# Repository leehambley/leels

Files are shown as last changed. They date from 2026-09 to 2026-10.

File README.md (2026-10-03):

# leels: single-axis electronic gearbox



A Rust/Embassy port of the gearbox mode of
[NanoEls H5](https://github.com/kachurovskiy/nanoels), cut down to one job:
the Z lead screw follows the spindle at the selected pitch. There is no WiFi,
no other modes, no X/Y axis, no keyboard or joystick, and no GCode.

```
els-core/   hardware-independent logic, no_std, host-tested (cargo test)
firmware/   esp-hal + esp-rtos (Embassy) binary; ESP32-C6 primary, ESP32-S3 secondary
hil/        hardware-in-the-loop tests: drive a board as the display would
docs/       Nextion page layout
```

## Build and flash

```sh
cd els-core && cargo test          # logic tests on the host

cd firmware
cargo run --release                # ESP32-C6 (default, stable Rust): build, flash, monitor
cargo build --release
cargo run --release --features setup-on-boot   # bench test without a display: hotspot at power-up
cargo +esp s3                      # ESP32-S3: needs the Xtensa toolchain (espup)
```

Board-specific values are in `firmware/src/config.rs`: pinout, motion timing,
display and hotspot settings, and `DEFAULTS`, the machine settings used until
you save your own. Machine settings are normally changed without recompiling,
from the setup page (below).
- **C6** pins (ESP32-C6-DevKitC-1): encoder A 10 / B 11 (Z reserved on 7, not read yet), STEP 18, DIR 19, ENA 20 (S2-SVD servo: wired straight to its opto inputs, see `config.rs`), Nextion TX 22 / RX 23. All are 3.3 V only.
- **C6 breadboard build** (`cargo run --release --features breadboard`), for
  test-driving on a solder breadboard with a 74HCT125 under the DevKit
  driving the servo at 5 V: STEP 18, DIR 8, encoder A 21 / B 15 with
  pull-ups fed from GPIO17 (RX, held high). No ENA: the S2-SVD's enable
  needs 24 V, which this setup doesn't have, so it isn't used (the drive
  enables itself). `config.rs` has the IC wiring. A PCB would use the normal
  pinout.
- **S3** pins: NanoEls H5 pinout (encoder 13/14, STEP 35, DIR 42, ENA 41, Nextion TX 43 / RX 44).

The spindle encoder has open-drain outputs, so the ESP32's internal pull-ups
(already enabled) pull A/B up to 3.3 V. No level shifting is needed on either
chip. For anything beyond slow speeds, fit external pull-ups: see
[Speed limits](#speed-limits-compared-with-nanoels-h5).

Logs go to USB-Serial-JTAG, which leaves both UARTs free.

### Breadboard build: servo wiring (S2-SVD CN2)

S2-SVD servo CN2, a 25-pin D-sub, 5 V only: pin 3 brown PP+ and pin 4 green PD+ to the 5 V rail, pin 14 blue PP minus from 74HCT125 pin 6 (STEP, GPIO18), pin 5 grey PD minus from 74HCT125 pin 8 (DIR, GPIO8). Pins 6, 9 and 10 unconnected.

| Breadboard | ESP32-C6 side | Wire | CN2 pin |
|---|---|---|---|
| POWER | 5 V rail | brown, green | 3 PP+, 4 PD+ |
| STEP | GPIO18 → 74HCT125 pin 6 (2Y) | blue | 14 PP− |
| DIR | GPIO8 → 74HCT125 pin 8 (3Y) | grey | 5 PD− |

- The drive's inputs are optocouplers (330 Ω + LED): a low on PP− or PD−
  sinks current from the 5 V rail through the LED and back to ground through
  the 74HCT125. STEP pulses low. Nothing here is above 5 V.
- No ENA: this servo's enable input needs 24 V, and this setup has nothing
  above 5 V, so it isn't used. Set **Pn003 = 1** (the drive enables itself
  at power-up) and leave CN2 6, 9 and 10 unconnected.
- The 74HCT125's OE pins (4 and 10) are tied to GND, so STEP and DIR are
  always passed through.
- **Before fitting the DevKit, cut its header pins 1, 2, 3, 9, 10, 12, 13
  and 19.** Their breadboard strips carry the 74HCT125's tie-offs (5 V,
  GND) or its 5 V outputs. 5 V reaches the ESP32 otherwise (GPIO12 is USB
  D−, and one board was lost this way), and a grounded GPIO9 holds the BOOT
  pin low, so the chip starts in download mode and looks dead. USB still
  works without them.

### Bench debugging without a display

```sh
cargo run --release --features bench
```

Logs all Nextion UART traffic (`nextion tx:` / `nextion rx:`) and repeats a
jog sequence (tap right, tap left, 2 s hold right, 2 s hold left) so STEP and
DIR can be scoped. It doesn't start the hotspot: setup mode
locks out jogging (add `setup-on-boot` for that separately).

### Hardware-in-the-loop tests

The `hil` firmware build takes Nextion touch events over the USB port, into
the same buffer the display's UART fills, so the touch parser, UI, motion
task, RMT and STEP pin all run for real. A second PCNT unit counts the pulses
on the STEP pin inside the chip (no wiring) and the count is logged next to
the planned position. The host tests in `hil/` reset the board, tap
components by their HMI object names, and assert on the text and colours the
firmware sends to the display and on the step counts.

```sh
cd firmware && cargo build --release --features hil
espflash flash --chip esp32c6 target/riscv32imac-unknown-none-elf/release/els
cd ../hil && LEELS_PORT=/dev/cu.usbmodem1101 cargo test
```

Without `LEELS_PORT` the tests are skipped. The `hil` build ignores saved
settings and doesn't read the Nextion UART, and the spindle isn't simulated
yet, so threading while engaged isn't covered. Plug the board straight into
the computer: through chains of hubs, flashing and the tests can fail.

## Operation

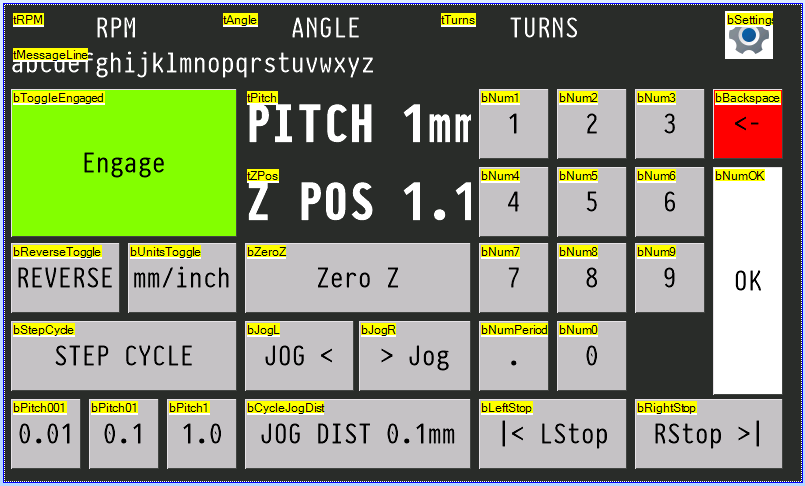
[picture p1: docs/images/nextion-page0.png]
Nextion Editor view of the 800 by 480 touch screen, each component labelled with its object name. Top row: RPM, ANGLE and TURNS readouts and a settings gear. Left: a large green Engage button, REVERSE, mm/inch, STEP CYCLE and pitch presets 0.01, 0.1 and 1.0. Middle: PITCH and Z POS readouts, Zero Z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


The screen layout in the Nextion Editor, with each component's object name.
See [docs/nextion.md](docs/nextion.md) for what each one does.

- **Pitch** is a number plus a unit. Type it on the keypad and press **OK**
  (the pending number shows in amber with a cursor; hold **<-** to clear it),
  or tap a preset (**0.01 / 0.05 / 0.1 / 0.5 / 1.0 / 5.0**). **REVERSE** flips direction.
  **UNIT** keeps the number and changes the unit (0.100 mm becomes 0.100").
  Pitch is capped at 1". Pitch can't be changed while engaged: disengage
  first.
- **Engage / Disengage** is one button: it closes the virtual half-nut at the
  current position, or opens it, stopping the lead screw immediately. The
  thread is kept while disengaged: jog back and engage again at the same pitch
  and the button shows `Syncing` until the spindle reaches the thread's phase,
  so the next pass follows the same groove (single-start threads). Changing
  the pitch while disengaged starts a new thread. Jog a little in the cutting
  direction before engaging to take up lead screw backlash.
- **Stops**: pressing Stop L or Stop R sets that stop at the current position.
  The button turns amber and shows the distance still to go to the stop; it turns red with `AT STOP`
  while the carriage rests on it. Pressing it again clears it, but only while
  disengaged or resting on the stop. Stops limit threading and jogging. The
  carriage parks on a stop while the spindle keeps turning. Reverse the
  spindle and it leaves the stop within one turn, still in thread phase. If
  you clear a stop while resting on it, the engage button shows `Syncing` and
  the carriage waits for the thread phase before moving on. **Zero Z** also
  clears both stops.
- **Jog** (disengaged only; refused with a beep while engaged): **Jog L / Jog R**
  move the carriage. Stops limit jogging too.
  - The jog distance (.01 / .1 / 1 / 10 in the current unit, cycled with its
    own button) also sets the jog speed: 0.5 / 2 / 8 / 25 mm/s.
  - A **tap** moves exactly the jog distance at that speed. Repeated taps add
    up.
  - A **hold** longer than 0.4 s runs continuously, starting at the same speed
    and stepping up one speed every second until 25 mm/s. Releasing brakes to
    a stop. Pressing the other direction while moving also brakes.
  - Speeds and timings are set on the setup page.
- **Setup** (only when disengaged and not jogging) turns on a WiFi hotspot,
  `LEELS-SETUP` with password `els-setup`. Both are shown on the display.
  Phones open the settings page automatically as a sign-in page; otherwise
  browse to `http://192.168.4.1/`. The page covers:
  - the encoder (lines, backlash, glitch filter, direction);
  - the lead screw and motor (pitch, steps, start/max speed, acceleration,
    backlash, largest pitch);
  - driver signals (DIR/ENABLE inversion, STEP polarity, pulse width, DIR
    setup time);
  - jog speeds and timings.

  **Backlash** is taken up on every reversal: the motor turns that much
  further, so the Z readout, stops and thread phase stay true. *Measure it*
  opens a wizard for a dial indicator on the carriage: it moves the carriage
  1 mm left, you zero the indicator, it moves 0.5 mm right, and you enter the
  reading. Each further round runs with the value so far switched on and
  refines it, until a round reads 0.5 mm within 0.005 mm. The carriage moves
  from the phone, so keep hands clear. At power-up the controller assumes the
  slack was last taken up moving left.

  **Save** checks the values, writes them to flash and restarts with WiFi off.
  Pressing Setup again leaves without saving. Pins stay fixed in the firmware.

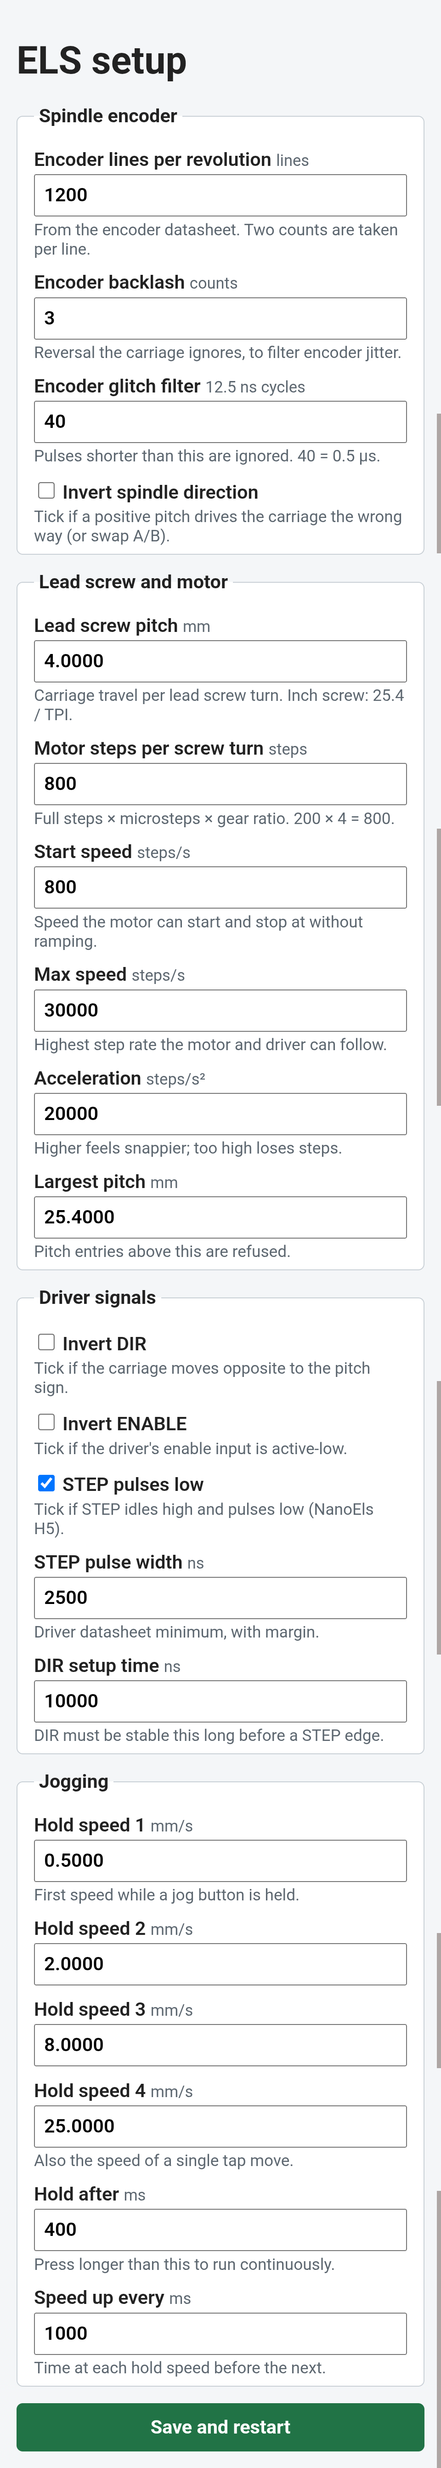
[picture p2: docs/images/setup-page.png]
Setup page on a phone: spindle encoder, lead screw and motor, driver signals and jogging settings, with a Save and restart button
  
- **Remembered across power-off:** pitch, unit, pitch step and jog distance.
  They're saved 3 s after the last change, once the carriage is idle. Stops
  and position are not saved, because the carriage may be moved while the
  controller is off.

## Saved data

Settings and operator state live in the first four sectors of the flash's NVS
partition, as raw records (not ESP-IDF NVS). Each record has:
- a **magic number**, so blank flash (`0xFF`) and random data are told apart;
- a **format version**, for migrations;
- the **length**, a **sequence number** and a **CRC32**.

Two slots per record are written alternately, and the newer valid one wins,
so a power cut during a save keeps the previous copy. Blank flash means
first boot, and the defaults are used. A damaged record, or one from a newer
firmware, also falls back to the defaults, and the display says so. Flash
writes pause the CPU for tens of milliseconds, so they only happen while
nothing moves.

## How motion works

Software plans the motion and hardware times the pulses: the same split as
LinuxCNC's stepgen or Klipper.

```
 PCNT spindle count ─► predict spindle position at end of next segment
                         │
       commands ───────► gearbox (engaged) or jog (disengaged) ─► target
                         │
                       StepGen: velocity/acceleration-limited plan for one
                       250 µs segment → exact STEP pulse times
                         │
                       RMT plays the segment in hardware (100 ns resolution)
                       while the next segment is planned
```

- `motion_task` runs on a high-priority interrupt executor, paced by the RMT
  peripheral. Each loop starts playing the segment planned last time, plans
  the next one, then waits for playback to finish. That's 4,000 wakeups a second.
- The gearbox target is `p_ref + (spindle − s_ref) · pitch·steps / (screw·counts)`,
  in exact integer maths, including the fraction of a step. It's evaluated at
  the spindle position predicted for the end of the segment, so the carriage
  doesn't lag the spindle.
- StepGen (`els-core/src/stepgen.rs`) sets each segment's velocity from:
  - feed-forward: how fast the target is moving;
  - a correction for any remaining error, limited so the error could still be
    braked away (`√(2·a·error)`).

  Velocity is constant within a segment, so pulses are evenly spaced. Host tests
  check a steady spindle gives step intervals within ±0.1 µs of ideal, and that
  a realistic spindle run-up never lags by more than 1 step.
- The maximum step rate is set by the pulse width and the driver (30 k steps/s
  configured), not by a software tick.
- The UI and display run on the normal thread executor. They talk to motion
  through a command channel and a status snapshot.

Known limitation: esp-hal's RMT driver restarts transmission for each
segment, which leaves a few-µs gap between segments. Position isn't affected,
because every step is still planned against the spindle. A gapless version
would need a custom RMT ring-buffer driver.

## Speed limits compared with NanoEls H5

Example machine: a 1200-line encoder driven 1:1 by the spindle (2400 counts
per revolution), 800 steps per screw turn, 4 mm screw (200 steps/mm).
Channel A then runs at **20 Hz per spindle rpm**, and at 1 mm pitch the motor
needs **3.33 steps/s per rpm**.

| | NanoEls H5 original (S3, Arduino) | leels on C6 (primary) | leels on S3 |
|---|---|---|---|
| CPU | 2 × 240 MHz; motion busy-loops on core 1 | 1 × 160 MHz, shared | 2 × 240 MHz; everything on core 0 |
| Encoder counting | PCNT hardware | PCNT hardware | PCNT hardware |
| Encoder glitch filter | 12.5 ns | 0.5 µs (settable) | 0.5 µs (settable) |
| STEP pulses made by | software in `loop()`, polling `micros()` | RMT hardware, 100 ns resolution | RMT hardware, 100 ns resolution |
| Step timing jitter | about one `loop()` pass plus 1 µs `micros()` steps; interrupts on core 1 add to it (estimated) | 0.1 µs within a segment; ~11 µs pause every 250 µs (measured) | same design; pause likely shorter (not measured) |
| Pulse width | length of the code between the two pin writes | exactly as set (2.5 µs default) | exactly as set |
| Step-rate ceiling from the controller | speed of `loop()`: tens of kHz, estimated | 30k steps/s as configured; ~128k possible (32 steps per segment) | same as C6 |
| CPU used by motion | all of core 1 | ~75 µs per 250 µs segment, ~30% (measured) | expected ~20% of core 0 at 240 MHz (not measured) |
| Lag behind the spindle | about one loop pass | ≤ 1 step during spin-up (host tests; position predicted ahead) | same as C6 |

**Maximum rpm is the same on all three.** With hardware pull-ups none of the
controllers is the limit. What is:

1. **The encoder's rated output frequency.** Cheap optical encoders are often
   rated around 100 kHz; check your datasheet. 100 kHz / 20 Hz per rpm =
   **5,000 rpm**. The PCNT counter itself handles MHz rates, and leels'
   0.5 µs glitch filter still passes up to about 1 MHz (50,000 rpm).
2. **The stepper at speed.** A typical stepper at 4× microstepping becomes
   unreliable around 10–15k steps/s (depends on supply voltage and load).
   That's about **3,000–4,500 rpm at 1 mm pitch** and **120–180 rpm at 1"**
   (85 steps/s per rpm). The same motor limits all three controllers.
3. **leels' `speed_max`** (30k steps/s by default) is about 9,000 rpm at
   1 mm pitch, so it's well clear of both.

### Pull-ups and encoder edges

An open-drain output only pulls low. The pull-up resistor and the capacitance
of the cable and input (roughly 100 pF per metre of cable) set how slowly each
edge rises. An input reads high at about 75% of 3.3 V, which takes about
1.4 × R × C.

| Pull-up to 3.3 V | Rise time (1 m cable, ~100 pF) | Rise time (3 m, ~300 pF) | rpm before edges get marginal* |
|---|---|---|---|
| internal, ~45 kΩ | ~6 µs | ~19 µs | ~4,000 (1 m), ~1,300 (3 m) |
| external 4.7 kΩ | ~0.7 µs | ~2 µs | encoder-limited (~5,000) |
| external 2.2 kΩ | ~0.3 µs | ~1 µs | encoder-limited (~5,000) |

\*Rise time equal to half a period of channel A: 1 / (2 × 20 Hz × rpm).
Before that point, slow edges can also count twice if noise crosses the
threshold. This applies equally to the original firmware, which used the
same internal pull-ups.

Use **2.2–4.7 kΩ to 3.3 V, not 5 V**: ESP32 inputs aren't 5 V tolerant, and
at 3.3 V the encoder only has to sink about 1.5 mA.

### Multiple cores

- **C6:** one main core; its second core is a 20 MHz low-power core that can't
  run any of this. Motion runs on a high-priority interrupt executor that
  preempts the display, touch and WiFi tasks, and uses ~30% of the core.
- **S3:** motion *can* be moved to core 1 (`esp_rtos::start_second_core`,
  then start the motion interrupt executor there). It **isn't needed for
  speed**: RMT times the pulses, and planning only has to finish within each
  250 µs segment, which it does with room to spare even on the C6. The only
  benefit would be isolating motion from WiFi interrupts on the S3. Flash
  writes stall both cores regardless, which is why saves only happen while
  idle. Worth doing only if an S3 build ever shows planning overruns.

## Not carried over

Saving stops and position across power-off, backlash compensation, TPI
entry, the max-travel E-stop, and enable/disable per axis.

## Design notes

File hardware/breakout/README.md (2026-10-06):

# Breakout board

A carrier for the ESP32-C6-DevKitC-1: the DevKit plugs into two 1x16 female
sockets (rows 22.86 mm apart) and sits about 8.5 mm above this board. All parts
are through-hole. The buffer IC, transistor, resistors and capacitors sit under
the DevKit, so keep them low: no IC socket, resistors flat.

- Left edge: encoder terminal (bottom to top: 5V, GND, A, B, Z) and shield
  GND terminal.
- Right edge: Nextion (JST-XH 4), servo terminal (5V, STEP, DIR, ENA, GND) and
  5 V in.
- The board stops where the DevKit's PCB stops, so nothing is under its
  antenna.

Firmware: the normal C6 build (`cargo run --release`), not `--features breadboard`.

## Regenerating the PCB

The schematic is the source. The board is rebuilt from it by script, then
routed with [Freerouting](https://github.com/freerouting/freerouting) 1.9.0:

```sh
KP=/Applications/KiCad/KiCad.app/Contents/Frameworks/Python.framework/Versions/3.9/bin/python3
kicad-cli sch export netlist --format kicadxml -o net.xml leels-breakout.kicad_sch
$KP build_pcb.py net.xml         # outline, placement, GND pours, stitching vias
$KP route.py export board.dsn
java -jar freerouting-1.9.0.jar -de board.dsn -do board.ses -mp 100 -inc Ground
$KP route.py import board.ses    # also refills the pours
kicad-cli pcb drc --schematic-parity --refill-zones leels-breakout.kicad_pcb
```

Placement lives in `build_pcb.py` (`PLACE`). GND is not routed; the pours on
both layers and the stitching vias carry it. Net classes (0.3 mm signals,
0.6 mm power and ground) are in `leels-breakout.kicad_pro`.

`leels.pretty/ESP32-C6-DevKitC-1_Sockets` is Espressif's DevKitC-1 footprint
with its courtyard limited to the socket rows, so parts may sit under the
DevKit.

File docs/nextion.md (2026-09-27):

# Nextion page layout

Only page 0 of the Lee-LS HMI (`nextion/lee-ls.HMI`, compiled as
`nextion/lee-ls.tft`) is used. The firmware identifies buttons by
**component id**. The ids live in `els-core/src/nextion.rs::id`; the Nextion
Editor renumbers every component after a deleted one, so re-check them
whenever the HMI changes. Nextion sends `65 00 <id> 01 FF FF FF` on press when *Send
Component ID* is ticked for the Touch Press Event. It writes text by
**objname**. The mapping lives in `els-core/src/nextion.rs::key_for`; the
written fields are in `els-core/src/display.rs::FIELDS`.

See `nextion-hmi-lee-ls.md` for the full component list with geometry,
and the history of the naming decisions.

## Buttons (touch press → action)

| id | objname | action |
|---:|---|---|
| 19 | bToggleEngaged | **Engage** the virtual half-nut when idle (refused while a number is being typed, in setup, or while jogging); **disengage** when engaged or syncing |
| 20 | bReverseToggle | **Reverse**: flip pitch direction |
| 21 | bUnitsToggle | Toggle **MM / IN** (number kept; refused if it would exceed 1") |
| 23 | bPitch001 | Set pitch to 0.01 (current unit and direction), a keypad shortcut |
| 33 | bPitch005 | Set pitch to 0.05 |
| 24 | bPitch01 | Set pitch to 0.1 |
| 34 | bPitch05 | Set pitch to 0.5 |
| 25 | bPitch1 | Set pitch to 1.0 |
| 35 | bPitch5 | Set pitch to 5.0 (inch: refused, over the 1" limit) |
| 6–8, 10–16 | bNum1…bNum9, bNum0 | Digits (`bNum1`=6, `bNum2`=7, `bNum3`=8, `bNum4`…`bNum9`=10…15, `bNum0`=16) |
| 18 | bNumPeriod | Decimal point |
| 9 | bBackspace | Delete the last typed character; **hold ≥ 0.7 s** (on release) to clear the whole entry. Needs press *and* release events |
| 17 | bNumOK | Apply typed pitch |
| 4 | bLeftStop | Set the Z left stop at the current position, or clear it (see *Stops* below) |
| 5 | bRightStop | Same for the right stop |
| 26 | bZeroZ | Zero the Z position readout **and clear both stops** (`Stops cleared` on the message line for 5 s or until the next press). Refused while engaged with a stop set |
| 27 | bJogL | **Jog left**; needs press *and* release events |
| 28 | bJogR | **Jog right**; needs press *and* release events |
| 29 | bCycleJogDist | Cycle jog distance .01 / .1 / 1 / 10 (current unit) |
| 31 | bSettings | Start / leave the WiFi setup hotspot |
| 2, 3 | tAngle, tTurns | Zero turns and angle readouts |

For the two jog buttons and `bBackspace`, tick *Send Component ID* on **both**
Touch Press and Touch Release events. Every other entry above only needs the
press event.

**Pitch is locked while the half-nut is engaged:** digits, `.`, OK, the pitch
presets, REVERSE and mm/inch beep and show `Disengage to change pitch`.

**Keypad entry:** while a number is typed but not yet applied, `tPitch` shows
it with a blinking cursor (`P1.25_`) on an amber background, and the
message line shows `OK to apply, <- delete, hold <- clear`. Any other button
drops the entry and shows `Entry cancelled`; a pitch preset simply replaces it.

**Setup mode:** while the hotspot is up, every touchable component except
`bSettings` has its touch events turned off (`tsw name,0`) and is drawn
near-black with dim grey text. Leaving setup restarts the firmware, which
sends `page 0` at boot to put back the HMI's own colours and touch settings.

## Text and fonts

Text is sent as UTF-8, the encoding of both fonts in the HMI. A font only
shows the glyphs it was generated with:

- **Font 0** (PragmataPro 30 px, all characters): everything except the two
  big readouts. Needs `°` for `tAngle`.
- **Font 1** (PragmataPro Bold 56 px, `tPitch` and `tZPos`): ASCII only.
  About 9 characters fit, which is why the readouts are `P-5.000mm` and
  `Z-999.995` rather than words (`PITCH_SYMBOL` / `Z_SYMBOL` in
  `els-core/src/display.rs`). The bold PragmataPro has almost no symbols;
  the regular weight has e.g. `∿` and `↔` if you ever regenerate the font.

## Text written by the firmware

| objname | content |
|---|---|
| bToggleEngaged | `Engage`, `Disengage` (engaged), `Syncing` (waiting for thread phase) or `Setup on` |
| tPitch | `P-1.250mm`; while typing `P1.25_` (blinking cursor, amber) |
| bReverseToggle | `NORMAL` (grey) / `REVERSE` (amber) |
| tMessageLine | (max 40 chars) the typed number (`Pitch 1.25`), warnings, `Set pitch`, `Waiting for thread phase`, and the hotspot name and password in setup mode |
| bUnitsToggle | `UNIT: MM` / `UNIT: IN` (max 10 chars) |
| tRPM | `RPM 1200` |
| tTurns | `TURNS 12.34`, spindle turns since engage (or last zero) |
| tAngle | `ANGLE 123.45°` |
| tZPos | `Z1.123` (mm 3 dp / inch 4 dp; no unit, see tPitch or UNIT) |
| bLeftStop | `\|< Set stop`, `\|< 12.345mm` (distance from the carriage to the stop), or `\|< AT STOP`; max 15 chars |
| bRightStop | `Set stop >\|`, `12.345mm >\|`, or `AT STOP >\|` |
| bCycleJogDist | idle: `JOG DIST 0.1mm`; tap move: `JOG 0.300mm` (distance still to go); hold: `HOLD SPEED 2/4`; braking: `STOPPING` |

Fields are only resent when their
text changes, plus a full refresh every 5 s.

## Stops

Each stop button has three states. The firmware sets the caption and the
background (`bco`) and text (`pco`) colours. Every pair meets WCAG AAA
(≥ 7:1 contrast) for poor workshop lighting; a unit test enforces it:

| State | Caption | `bco` | Tap |
|---|---|---|---|
| Not set | `\|< Set stop` | grey `50712` / black text (11.9:1) | set the stop at the current position |
| Set | `\|< 12.345mm` = the stop's Z position (same zero and units as `tZPos`) | amber `64896` / black text (11.6:1) | clear it, **only while disengaged**; otherwise beep + `Stop armed: wait or disengage` |
| Parked (carriage is at the stop) | `\|< AT STOP` | dark red `40960` / white text (8.1:1) | clear it: when threading, the carriage waits for thread phase and continues |

"Parked" means the motor position equals the stop: either a threading pass
ended there, or a jog ran into it.

Messages on `tMessageLine` disappear after their timeout or on the next
button press (jog releases don't count).

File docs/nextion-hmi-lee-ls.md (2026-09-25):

# Lee-LS HMI → firmware mapping

> **Historical.** This compared an earlier revision of the HMI with the
> firmware before it was adapted. The committed HMI (`nextion/lee-ls.HMI`)
> has a different layout, no `tSpeed`, an added `tMessageLine`, and ids shifted
> by one. `docs/nextion.md` is the current reference.

This compares `Lee-LS HMI.grid.HMI` (page 0, 33 components) with the
current firmware: `els-core/src/nextion.rs::key_for`, the `Key` enum in
`els-core/src/ui.rs`, `els-core/src/display.rs::FIELDS`, and
`docs/nextion.md`.

**Status:** §2, §3 and §5 are implemented in `els-core`, using the
decisions: bPitch buttons are pitch presets (`Key::PitchPreset`), messages
go to the added `tMessageLine` (40 chars), `tSpeed` is dropped (remove it from the HMI).

Component ids come from the HMI's `id` attribute (hex in the file,
decimal below). The grid version has the same ids as the original.

> **Check in the Editor:** the "Send Component ID" flags on the Touch
> Press/Release events were not decoded from the HMI. Every button below
> needs *Press* ticked. `bJogL`/`bJogR` also need *Release* ticked, and so
> do `tTurns`/`tAngle` if they stay tappable.

## 1. Component list

| id | objname | type | label in HMI | font | geometry (x,y w×h) |
|---:|---|:-:|---|:-:|---|
| 1 | `tRPM` | t | RPM | 0 | 14,6 148×30 |
| 2 | `tSpeed` | t | SPEED | 0 | 170,6 148×30 (dropped, to be removed) |
| 3 | `tAngle` | t | ANGLE | 0 | 326,6 148×30 |
| 4 | `tTurns` | t | TURNS | 0 | 482,6 148×30 |
| 5 | `bLeftStop` | b | \|< LStop | 0 | 482,396 148×70 |
| 6 | `bRightStop` | b | RStop >\| | 0 | 638,396 148×70 |
| 7 | `bNum1` | b | 1 | 0 | 482,84 70×70 |
| 8 | `bNum2` | b | 2 | 0 | 560,84 70×70 |
| 9 | `bNum3` | b | 3 | 0 | 638,84 70×70 |
| 10 | `bBackspace` | b | <- | 0 | 716,84 70×70 |
| 11 | `bNum4` | b | 4 | 0 | 482,162 70×70 |
| 12 | `bNum5` | b | 5 | 0 | 560,162 70×70 |
| 13 | `bNum6` | b | 6 | 0 | 638,162 70×70 |
| 14 | `bNum7` | b | 7 | 0 | 482,240 70×70 |
| 15 | `bNum8` | b | 8 | 0 | 560,240 70×70 |
| 16 | `bNum9` | b | 9 | 0 | 638,240 70×70 |
| 17 | `bNum0` | b | 0 | 0 | 560,318 70×70 |
| 18 | `bNumOK` | b | OK | 0 | 716,162 70×226 |
| 19 | `bNumPeriod` | b | . | 0 | 482,318 70×70 |
| 20 | `bToggleEngaged` | b | Engage | 0 | 14,84 226×148 |
| 21 | `bReverseToggle` | b | REVERSE | 0 | 14,240 109×70 |
| 22 | `bUnitsToggle` | b | mm/inch | 0 | 131,240 109×70 |
| 23 | `bStepCycle` | b | STEP CYCLE | 0 | 14,318 226×70 |
| 24 | `tPitch` | t | PITCH 1mm | 1 | 248,84 226×70 |
| 25 | `bPitch001` | b | 0.01 | 0 | 14,396 70×70 |
| 26 | `bPitch01` | b | 0.1 | 0 | 92,396 70×70 |
| 27 | `bPitch1` | b | 1.0 | 0 | 170,396 70×70 |
| 28 | `bZeroZ` | b | Zero Z | 0 | 248,240 226×70 |
| 29 | `bJogL` | b | JOG < | 0 | 248,318 109×70 |
| 30 | `bJogR` | b | > Jog | 0 | 365,318 109×70 |
| 31 | `bCycleJogDist` | b | JOG DIST 0.1mm | 0 | 248,396 226×70 |
| 32 | `tZPos` | t | Z POS 1.123mm | 1 | 248,162 226×70 |
| 33 | `bSettings` | b | CFG | 0 | 716,6 70×70 |

## 2. Touch → `Key` mapping

**Status** key:
- ✅ same action; only the id or name changed
- 🆕 needs a new `Key` variant or new logic
- ❓ needs your decision

| id | objname | → Key | old firmware id / name | status |
|---:|---|---|---|:-:|
| 7–9, 11–16, 17 | `bNum1`…`bNum9`, `bNum0` | `Digit(n)` | 26–35, `b0`…`b9` | ✅ ids are **no longer contiguous**, so `c @ 26..=35` must become an explicit table (§5) |
| 19 | `bNumPeriod` | `Point` | 52 `bPoint` | ✅ |
| 10 | `bBackspace` | `Backspace` | 24 `bBack` | ✅ |
| 18 | `bNumOK` | `Enter` | 51 `bEnter` | ✅ |
| 20 | `bToggleEngaged` | **`ToggleEngage`** | 25 `bOn` / 23 `bOff` / 3 `bStatus` | 🆕 one button replaces three: engage when off, disengage when on or syncing. Keep the "refused while typing" rule for the engage direction. |
| 21 | `bReverseToggle` | `Reverse` | 5 `bReverse` | ✅ |
| 22 | `bUnitsToggle` | `ToggleUnit` | 6 `bMeasure` | ✅ |
| 23 | `bStepCycle` | `CycleStep` | 7 `tStepVal` | ✅ |
| 25 | `bPitch001` (0.01) | `StepSize(1)` | 54 `bStep01` | ❓ see §4.1 |
| 26 | `bPitch01` (0.1) | `StepSize(2)` | 55 `bStep1` | ❓ see §4.1 |
| 27 | `bPitch1` (1.0) | `StepSize(3)` | 56 `bStep10` | ❓ see §4.1 |
| 5 | `bLeftStop` | `StopLeft` | 40 `bStopL` | ✅ |
| 6 | `bRightStop` | `StopRight` | 41 `bStopR` | ✅ |
| 28 | `bZeroZ` | `ZeroZ` | 21 `bZ0` | ✅ |
| 29 | `bJogL` | `Jog { left: true, .. }` | 48 `bLeft` | ✅ press **and** release |
| 30 | `bJogR` | `Jog { left: false, .. }` | 49 `bRight` | ✅ press **and** release |
| 31 | `bCycleJogDist` | `JogCycle` | 58 `bJogDist` | ✅ |
| 33 | `bSettings` | `Setup` | 59 `bSetup` | ✅ |
| 3, 4 | `tAngle`, `tTurns` | `ZeroTurns` | 10, 9 (same names) | ✅ ids changed (10→3, 9→4) |
| 1, 2, 24, 32 | `tRPM`, `tSpeed`, `tPitch`, `tZPos` | none | none | not touch targets |

**Firmware keys with no HMI button:**

| Key | old id / name | note |
|---|---|---|
| `Plus` | 42 `bPlus` | ❓ no +/- buttons, see §4.1 |
| `Minus` | 43 `bMinus` | ❓ |
| `StepSize(0)` (0.001) | 53 `bStep001` | only reachable through `bStepCycle` |
| `StepSize(4)` (10) | 57 `bStep100` | only reachable through `bStepCycle` |
| `Engage` / `Disengage` | 25 / 23 | replaced by `ToggleEngage`. Keep them internally if the web UI or other code uses them. |

## 3. Text written by the firmware (`display.rs::FIELDS`)

| Firmware field | Content today | New target | status |
|---|---|---|:-:|
| `bStatus` | `OFF`/`ON`/`SYN`/`SET` | `bToggleEngaged.txt` | 🆕 suggest showing the action or state on the big button, e.g. `ENGAGE` when off, `ON` / `SYNC…` / `SETUP` otherwise |
| `tPitch` | `-1.250` | `tPitch.txt` | ✅ name matches. The HMI placeholder is `PITCH 1mm`, so the firmware probably needs to prefix/suffix it (`PITCH -1.250mm`). |
| `bMeasure` | `MM`/`IN` | `bUnitsToggle.txt` | ✅ rename |
| `tStepVal` | `0.001`…`10` | `bStepCycle.txt`? | ❓ no dedicated field. Suggest `STEP 0.1` on the cycle button. |
| `tRPMVal` | rpm | `tRPM.txt` | 🆕 one field holds label and value, e.g. `RPM 1200` |
| `tTurnsVal` | turns | `tTurns.txt` | 🆕 e.g. `TURNS 12.34` |
| `tAngleVal` | angle ° | `tAngle.txt` | 🆕 e.g. `ANGLE 123.45°` |
| none | none | `tSpeed.txt` | dropped: not a firmware value (the H5 had no speed field either) |
| `tZ` | Z position | `tZPos.txt` | ✅ rename. Placeholder `Z POS 1.123mm` suggests the same prefix/suffix treatment as `tPitch`. |
| `tZLeft` | distance to left stop | `bLeftStop.txt`? | ❓ no field. Could show `\|< 12.345` once set and `\|< LStop` when unset. |
| `tZRight` | distance to right stop | `bRightStop.txt`? | ❓ as above |
| `tJogVal` | `0.01`…`10` | `bCycleJogDist.txt` | 🆕 placeholder is `JOG DIST 0.1mm` |
| `t3` | typed number, warnings, `Set pitch`, hotspot SSID/password | **none** | ❓ biggest gap, see §4.2 |

## 4. Open decisions

### 4.1 Pitch step buttons without +/-

`StepSize` only affects `Plus`/`Minus`, and the HMI has no +/- buttons.
The buttons labelled `0.01`, `0.1`, and `1.0` therefore do nothing
visible under the current firmware. Options:

- **a)** Add `bPitchPlus`/`bPitchMinus` to the HMI. There is no free
  cell in the grid, so something would have to shrink.
- **b)** Make them *pitch presets*: tapping `1.0` sets pitch to 1.0 mm.
  This needs a new `Key::PitchPreset(milli)`.
- **c)** Make them the **jog distance** selector instead, and drop
  `bCycleJogDist`. The values match `JOG_SIZES_MILLI` (0.01/0.1/1/10
  minus 10).
- **d)** Leave them as step-size selectors for a future +/- (knob or
  encoder).

`bStepCycle` has the same issue: it cycles a step size that nothing uses
until +/- exists.

### 4.2 No message line (`t3`)

`t3` carries:
- the number being typed (`Pitch 1.25`), the only feedback while using
  the keypad;
- warnings ("refused while typing", unit overflow);
- `Set pitch`;
- `Waiting for thread phase`;
- the setup hotspot name and password.

Options:

- **a)** While typing, and for timed messages, show them in `tPitch`
  (it is the biggest text field and sits next to the keypad), then
  revert to the pitch. Show setup credentials there too while
  `setup_active()`. This needs firmware only.
- **b)** Add a message text field to the HMI, e.g. a 1-row strip. The
  grid has no free row, so something has to shrink.

(a) seems the better fit for this layout.

### 4.3 Status display

With `bStatus` gone, the toggle button's own text is the only engaged
indicator. The HMI could also change its `bco` when engaged: the
firmware would send `bToggleEngaged.bco=<rgb565>`. `encode_text` only
does `.txt`, so a small `encode_num` would be needed.

## 5. Suggested `key_for`

```rust
pub fn key_for(touch: Touch) -> Option<Key> {
    if touch.page != 0 {
        return None;
    }
    match touch.component {
        29 => return Some(Key::Jog { left: true, pressed: touch.pressed }),  // bJogL
        30 => return Some(Key::Jog { left: false, pressed: touch.pressed }), // bJogR
        _ if !touch.pressed => return None,
        _ => {}
    }
    Some(match touch.component {
        7 => Key::Digit(1),
        8 => Key::Digit(2),
        9 => Key::Digit(3),
        11 => Key::Digit(4),
        12 => Key::Digit(5),
        13 => Key::Digit(6),
        14 => Key::Digit(7),
        15 => Key::Digit(8),
        16 => Key::Digit(9),
        17 => Key::Digit(0),
        19 => Key::Point,        // bNumPeriod
        10 => Key::Backspace,    // bBackspace
        18 => Key::Enter,        // bNumOK
        20 => Key::ToggleEngage, // bToggleEngaged (new variant)
        21 => Key::Reverse,      // bReverseToggle
        22 => Key::ToggleUnit,   // bUnitsToggle
        23 => Key::CycleStep,    // bStepCycle
        25 => Key::StepSize(1),  // bPitch001 "0.01"  -- see 4.1
        26 => Key::StepSize(2),  // bPitch01  "0.1"
        27 => Key::StepSize(3),  // bPitch1   "1.0"
        5 => Key::StopLeft,      // bLeftStop
        6 => Key::StopRight,     // bRightStop
        28 => Key::ZeroZ,        // bZeroZ
        31 => Key::JogCycle,     // bCycleJogDist
        33 => Key::Setup,        // bSettings
        3 | 4 => Key::ZeroTurns, // tAngle, tTurns
        _ => return None,
    })
}
```

And the matching `FIELDS`, pending §4:

```rust
pub const FIELDS: [&str; N] = [
    "bToggleEngaged", // status
    "tPitch",
    "bUnitsToggle",   // was bMeasure
    "bStepCycle",     // was tStepVal
    "tRPM",           // was tRPMVal
    "tTurns",         // was tTurnsVal
    "tAngle",         // was tAngleVal
    "tZPos",          // was tZ
    "bLeftStop",      // was tZLeft
    "bRightStop",     // was tZRight
    "bCycleJogDist",  // was tJogVal
    "tSpeed",         // new
    // t3 message line: see 4.2
];
```

`docs/nextion.md` also describes the old H5-derived ids ("ids below 51
are the existing NanoEls H5 ids"). That no longer holds: this HMI
renumbers from 1. Update or replace it once the decisions above are made.

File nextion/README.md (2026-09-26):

# Nextion display files

| File | What |
|---|---|
| `lee-ls.HMI` | Nextion Editor project for the 800×480 NX8048P050-011R-Y display. Edit this. |
| `lee-ls.tft` | The same project compiled by the Nextion Editor, ready to load onto the display. |
| `SHA256SUMS` | Checksums of both, so you can tell the pair belongs together (`shasum -a 256 -c SHA256SUMS`). |

The `.tft` was compiled from this exact `.HMI`: every component's geometry in
the HMI appears in the `.tft`'s compiled page, and its compiled components
are in the HMI's id order (1–35).

**When you change the HMI:** recompile the `.tft`, replace both files
together, and regenerate `SHA256SUMS`. If you added or deleted a component,
the Editor renumbers everything after it: update the ids in
`els-core/src/nextion.rs` (`mod id`) and `docs/nextion.md` to match.

To load the `.tft`, copy it to a FAT32 microSD card, put the card in the
display and power it up, or upload it over serial from the Nextion Editor.

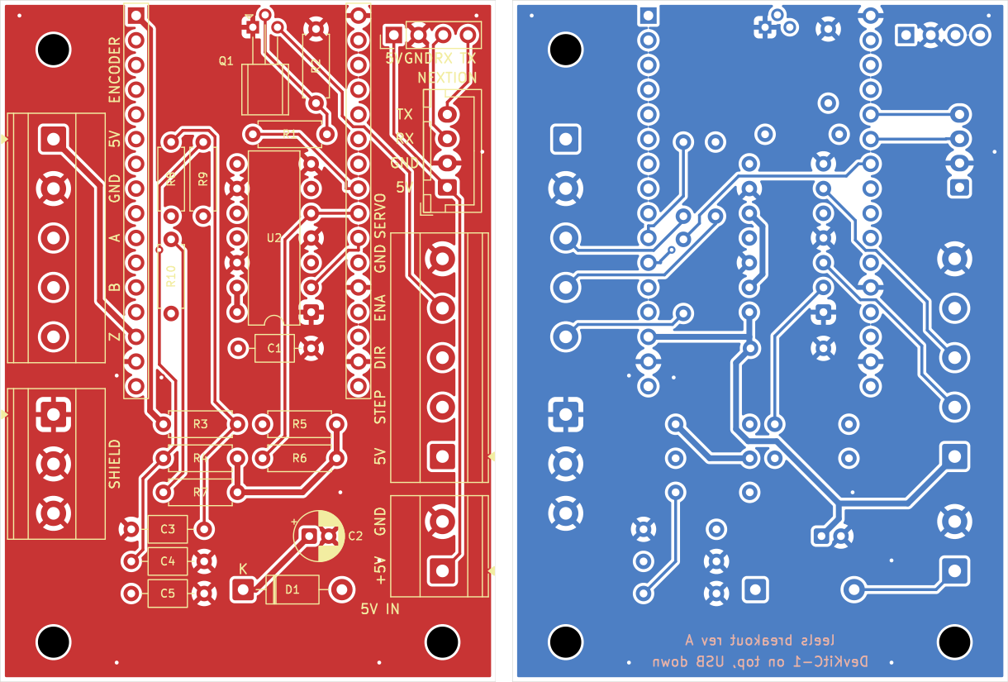
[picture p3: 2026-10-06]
hardware/breakout/leels-breakout-pcb.png

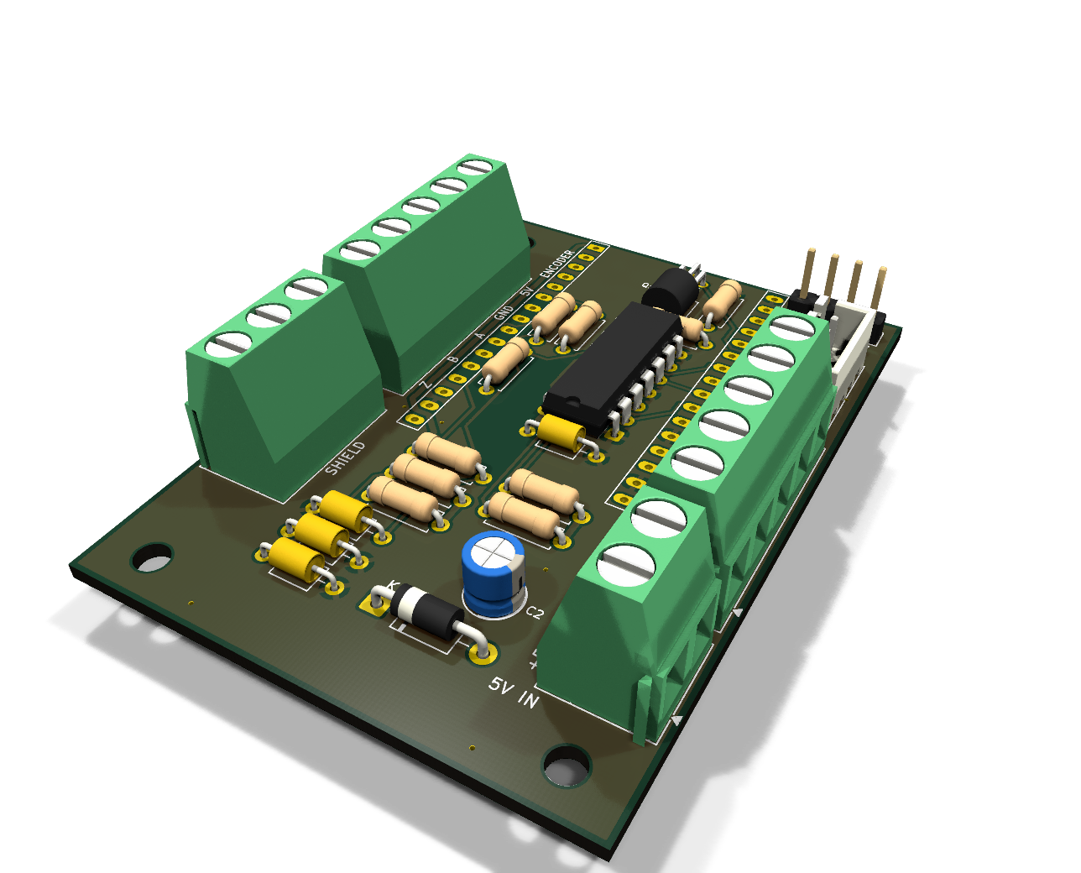
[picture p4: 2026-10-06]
hardware/breakout/leels-breakout-3d.png

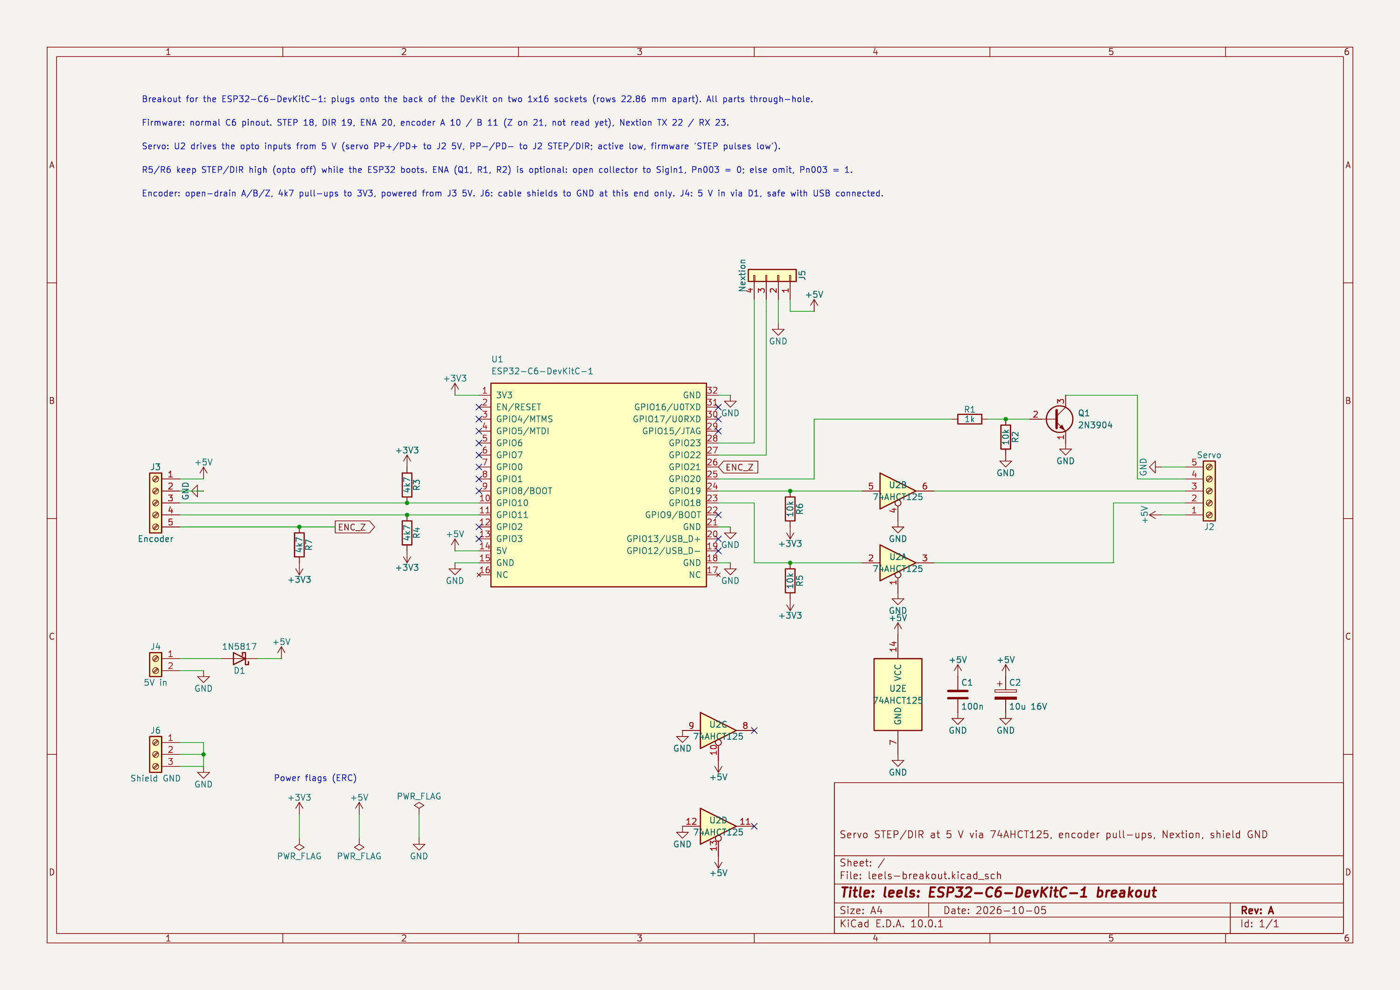
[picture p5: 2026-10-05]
hardware/breakout/leels-breakout.png

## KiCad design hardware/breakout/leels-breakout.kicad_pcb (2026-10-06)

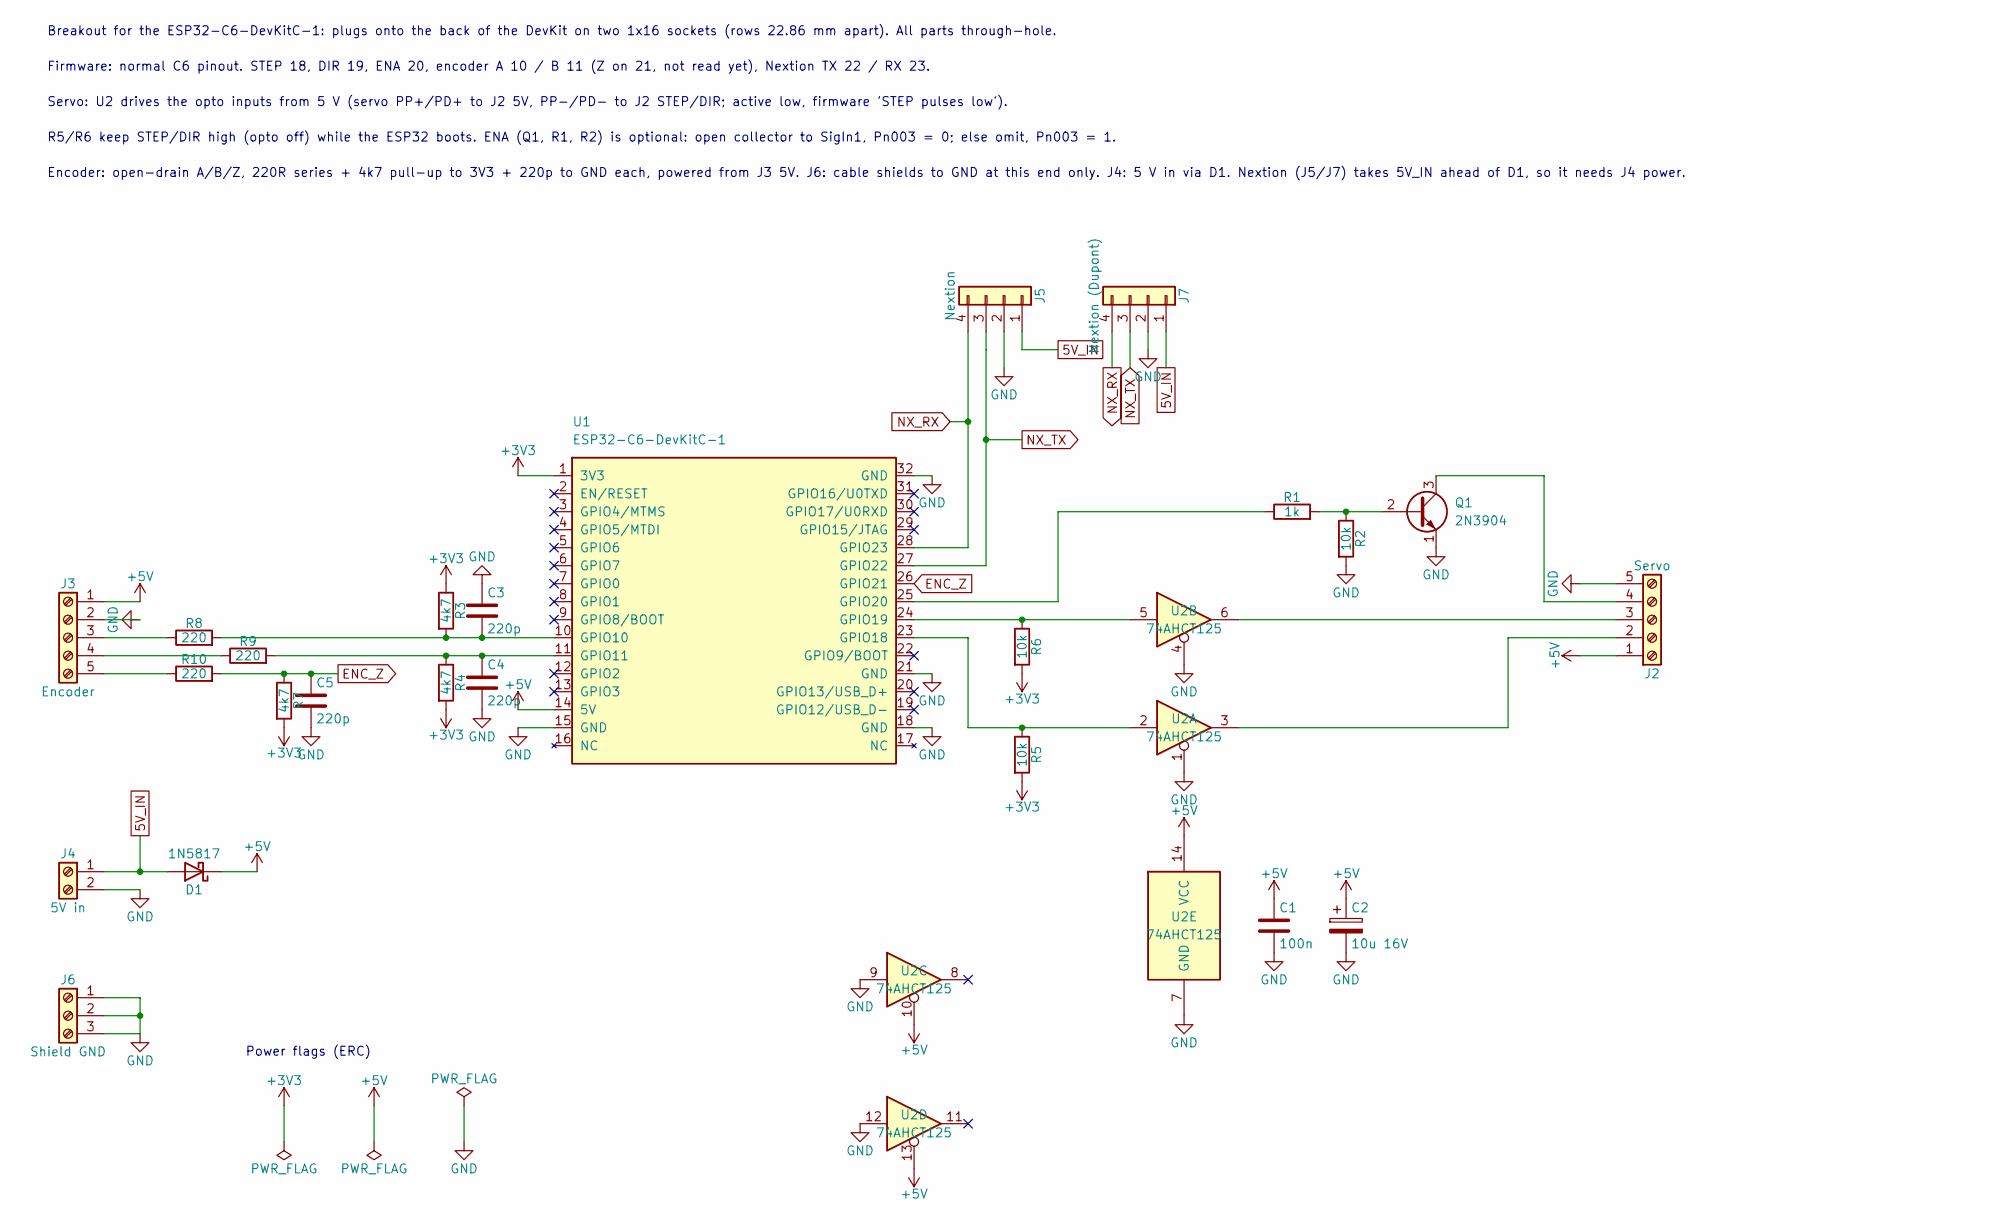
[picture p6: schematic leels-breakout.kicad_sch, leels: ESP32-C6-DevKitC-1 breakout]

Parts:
C1: 100n; C_Axial_L3.8mm_D2.6mm_P7.50mm_Horizontal
C2: 10u 16V; CP_Radial_D5.0mm_P2.00mm
C3, C4, C5: 220p; C_Axial_L3.8mm_D2.6mm_P7.50mm_Horizontal
D1: 1N5817; D_DO-41_SOD81_P10.16mm_Horizontal
J2: Servo; TerminalBlock_Phoenix_MKDS-1,5-5-5.08_1x05_P5.08mm_Horizont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
J3: Encoder; TerminalBlock_Phoenix_MKDS-1,5-5-5.08_1x05_P5.08mm_Horizont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
J4: 5V in; TerminalBlock_Phoenix_MKDS-1,5-2-5.08_1x02_P5.08mm_Horizont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
J5: Nextion; JST_XH_B4B-XH-A_1x04_P2.50mm_Vertical
J6: Shield GND; TerminalBlock_Phoenix_MKDS-1,5-3-5.08_1x03_P5.08mm_Horizont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
J7: Nextion (Dupont); PinHeader_1x04_P2.54mm_Vertical
Q1: 2N3904; TO-92_W4.0mm_StaggerEven_Horizontal_FlatSideDown
R1: 1k; R_Axial_DIN0207_L6.3mm_D2.5mm_P7.62mm_Horizontal
R2, R5, R6: 10k; R_Axial_DIN0207_L6.3mm_D2.5mm_P7.62mm_Horizontal
R3, R4, R7: 4k7; R_Axial_DIN0207_L6.3mm_D2.5mm_P7.62mm_Horizontal
R8, R9, R10: 220; R_Axial_DIN0207_L6.3mm_D2.5mm_P7.62mm_Horizontal
U1: ESP32-C6-DevKitC-1; ESP32-C6-DevKitC-1_Sockets
U2: 74AHCT125; DIP-14_W7.62mm

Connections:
5V_IN: D1.2 (A), J4.1, J5.1, J7.1
+3V3: R3.1, R4.2, R5.2, R6.2, R7.2, U1.1 (3V3)
+5V: C1.1, C2.1, D1.1 (K), J2.1, J3.1, U1.14 (5V), U2.10, U2.13, U2.14 (VCC)
ENC_Z: C5.1, R7.1, R10.2, U1.26 (GPIO21)
GND: C1.2, C2.2, C3.1, C4.2, C5.2, J2.5, J3.2, J4.2, J5.2, J6.1, J6.2, J6.3, J7.2, Q1.1 (E), R2.2, U1.15 (GND), U1.18 (GND), U1.21 (GND), U1.32 (GND), U2.1, U2.4, U2.7 (GND), U2.9, U2.12
NX_RX: J5.4, J7.4, U1.28 (GPIO23)
NX_TX: J5.3, J7.3, U1.27 (GPIO22)
unnamed: J2.2, U2.3
unnamed: J2.3, U2.6
unnamed: J2.4, Q1.3 (C)
unnamed: J3.3, R8.1
unnamed: J3.4, R9.1
unnamed: J3.5, R10.1
unnamed: Q1.2 (B), R1.2, R2.1
unnamed: C3.2, R3.2, R8.2, U1.10 (GPIO10)
unnamed: C4.1, R4.1, R9.2, U1.11 (GPIO11)
unnamed: R5.1, U1.23 (GPIO18), U2.2
unnamed: R6.1, U1.24 (GPIO19), U2.5
unnamed: R1.1, U1.25 (GPIO20)

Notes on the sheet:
Breakout for the ESP32-C6-DevKitC-1: plugs onto the back of the DevKit on two 1x16 sockets (rows 22.86 mm apart). All parts through-hole.
Firmware: normal C6 pinout. STEP 18, DIR 19, ENA 20, encoder A 10 / B 11 (Z on 21, not read yet), Nextion TX 22 / RX 23.
Servo: U2 drives the opto inputs from 5 V (servo PP+/PD+ to J2 5V, PP-/PD- to J2 STEP/DIR; active low, firmware 'STEP pulses low').
R5/R6 keep STEP/DIR high (opto off) while the ESP32 boots. ENA (Q1, R1, R2) is optional: open collector to SigIn1, Pn003 = 0; else omit, Pn003 = 1.
Encoder: open-drain A/B/Z, 220R series + 4k7 pull-up to 3V3 + 220p to GND each, powered from J3 5V. J6: cable shields to GND at this end only. J4: 5 V in via D1. Nextion (J5/J7) takes 5V_IN ahead of D1, so it needs J4 power.
Power flags (ERC)

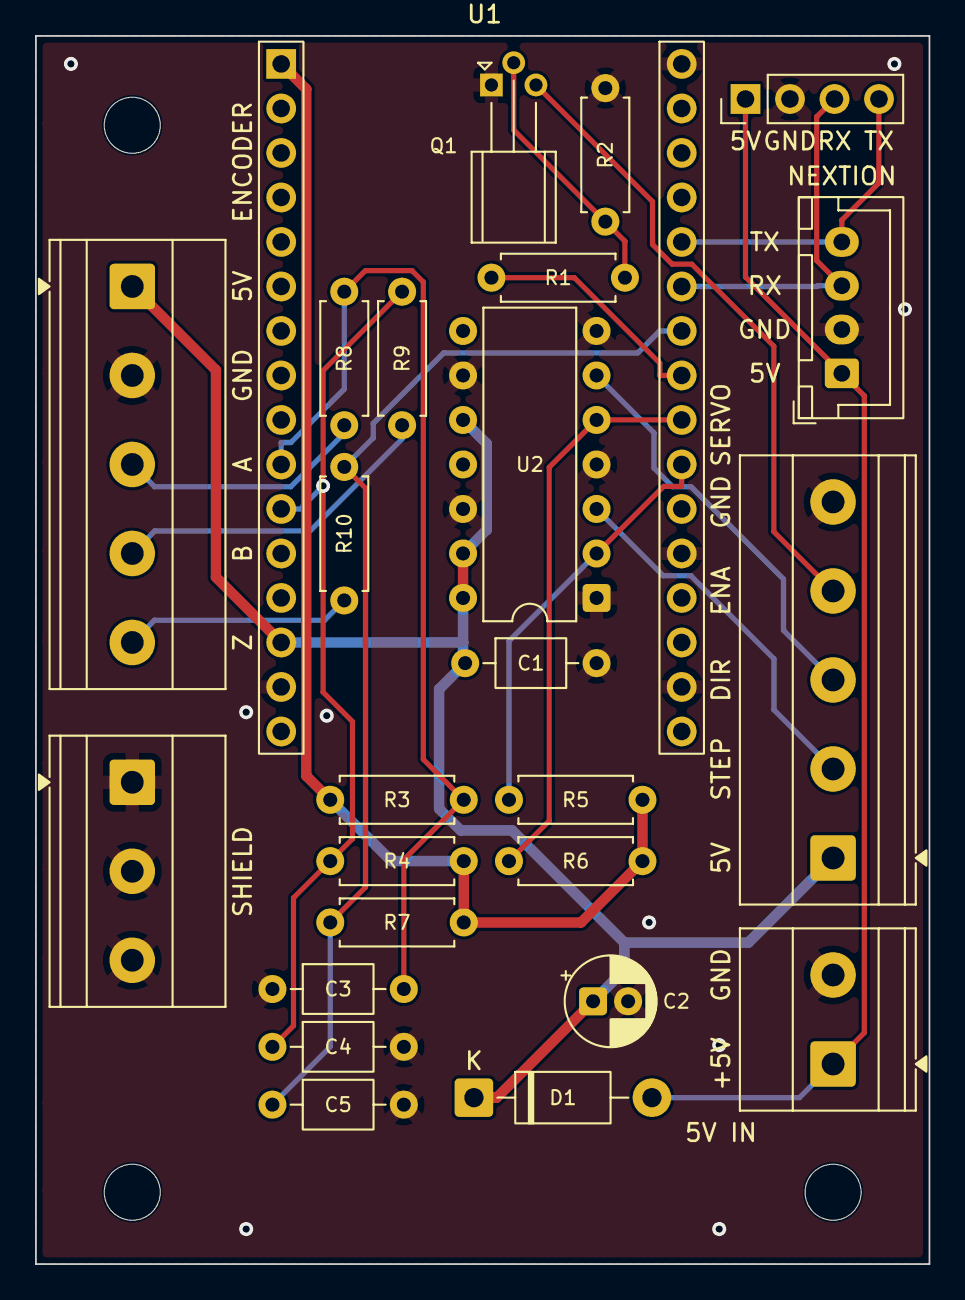
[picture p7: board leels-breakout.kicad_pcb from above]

Board: 2 copper layers, 51.0 x 70.1 mm, 28 parts (0 on the bottom side), 19 nets.

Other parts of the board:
H1, H2, H3: MountingHole_3.2mm_M3

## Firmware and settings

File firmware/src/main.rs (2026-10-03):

//! Single-axis electronic gearbox: the Z lead screw follows the spindle at the
//! selected pitch while the virtual half-nut is engaged.
//!
//! Motion pipeline (all on a high-priority interrupt executor):
//!
//! ```text
//!  PCNT spindle count ──► predict spindle at end of next segment
//!                           │
//!        commands ────────► gearbox (engaged) or jog (disengaged) ──► target
//!                           │
//!                         StepGen: velocity/accel-limited plan for one
//!                         segment → exact STEP pulse times
//!                           │
//!                         RMT plays the segment in hardware (100 ns
//!                         resolution) while the next one is planned
//! ```
//!
//! The loop is paced by RMT: each iteration starts playing the segment
//! planned last time, plans the following one, then waits for playback to
//! finish. The UI and display run as ordinary tasks on the thread executor.
#![no_std]
#![no_main]

extern crate alloc;

#[macro_use]
mod config;
#[cfg(feature = "hil")]
mod hil;
#[cfg(feature = "esp32c6")]
mod led;
mod setup;
mod storage;

use core::cell::Cell;

use els_core::backlash::Backlash;
use els_core::display::{self, Status, Text, COLOUR_FIELDS, FIELDS};
use els_core::gearbox::{Gearbox, Side};
use els_core::jog::{Bounds, Jog, JogView};
use els_core::nextion::{self, Parser};
use els_core::settings::{Origin, Settings};
use els_core::spindle::Spindle;
use els_core::stepgen::{Segment, StepGen, StepGenConfig, MAX_STEPS_PER_SEGMENT};
use els_core::ui::{Action, Command, Key, Ui};
use embassy_executor::Spawner;
use embassy_futures::select::{select3, Either3};
use embassy_sync::blocking_mutex::raw::CriticalSectionRawMutex;
use embassy_sync::blocking_mutex::Mutex;
use embassy_sync::channel::Channel;
use embassy_sync::pipe::Pipe;
use embassy_time::{Duration, Instant, Timer};
use esp_backtrace as _;
use esp_hal::clock::CpuClock;
use esp_hal::gpio::{Flex, Input, InputConfig, Level, Output, OutputConfig, Pull};
use esp_hal::interrupt::software::SoftwareInterruptControl;
use esp_hal::interrupt::Priority;
use esp_hal::pcnt::{channel, unit::Unit, Pcnt};
use esp_hal::rmt::{self, PulseCode, Rmt, TxChannelConfig, TxChannelCreator};
use esp_hal::time::Rate;
use esp_hal::timer::timg::TimerGroup;
use esp_hal::uart::{self, Uart};
use esp_hal::Async;
use esp_println::println;
use esp_rtos::embassy::InterruptExecutor;
use static_cell::StaticCell;

esp_bootloader_esp_idf::esp_app_desc!();

static COMMANDS: Channel<CriticalSectionRawMutex, Command, 16> = Channel::new();
static KEYS: Channel<CriticalSectionRawMutex, Key, 16> = Channel::new();
/// Bytes from the display, parsed into touch events by `touch_task`. Filled
/// from the Nextion UART, or from USB in `hil` builds.
static NEXTION_RX: Pipe<CriticalSectionRawMutex, 128> = Pipe::new();
/// Bytes for the display, written to the UART by `display_task`. Big enough
/// for a full refresh queued while the display boots.
static NEXTION_TX: Pipe<CriticalSectionRawMutex, 1024> = Pipe::new();
static STATUS: Mutex<CriticalSectionRawMutex, Cell<Status>> = Mutex::new(Cell::new(Status {
    engaged: false,
    syncing: false,
    jogging: false,
    jog: JogView::Idle,
    pos: 0,
    z_zero: 0,
    left_stop: None,
    right_stop: None,
    rpm: 0,
    turn_counts: 0,
}));

/// STEP levels: (active, idle).
fn step_levels(s: &Settings) -> (Level, Level) {
    if s.step_active_low {
        (Level::Low, Level::High)
    } else {
        (Level::High, Level::Low)
    }
}

/// RMT items for one segment: one per step plus the trailing idle/end item.
type Codes = heapless::Vec<PulseCode, { MAX_STEPS_PER_SEGMENT + 1 }>;

struct MotionHw {
    spindle: Unit<'static, 0>,
    // The RMT channel handle isn't `Send`, so it's configured inside the task.
    rmt: esp_hal::peripherals::RMT<'static>,
    step: esp_hal::gpio::interconnect::OutputSignal<'static>,
    #[cfg(feature = "hil")]
    step_counter: hil::StepCounter,
    dir: Flex<'static>,
    // Held so the pins stay configured.
    _enable: Option<Output<'static>>,
    _encoder_a: Input<'static>,
    _encoder_b: Input<'static>,
}

#[esp_rtos::main]
async fn main(spawner: Spawner) {
    #[allow(unused_mut)]
    let mut p = esp_hal::init(esp_hal::Config::default().with_cpu_clock(CpuClock::max()));
    let timg0 = TimerGroup::new(p.TIMG0);
    let sw = SoftwareInterruptControl::new(p.SW_INTERRUPT);
    #[cfg(feature = "esp32c6")]
    esp_rtos::start(timg0.timer0, sw.software_interrupt0);
    #[cfg(feature = "esp32s3")]
    esp_rtos::start(timg0.timer0);
    println!("ELS gearbox starting");

    // Heap for the WiFi stack (only used in setup mode).
    esp_alloc::heap_allocator!(#[esp_hal::ram(reclaimed)] size: 64 * 1024);
    esp_alloc::heap_allocator!(size: 36 * 1024);

    assert_eq!(config::DEFAULTS.validate(config::TIMING), Ok(()), "config::DEFAULTS are invalid");
    let mut store = storage::Store::new(p.FLASH);
    let (settings, origin) = store.load_settings(config::DEFAULTS, config::TIMING);
    let operator_state = store.load_state(settings.max_pitch_du as i64);
    // Tests start from the defaults every time, whatever is saved on the board.
    #[cfg(feature = "hil")]
    let (settings, origin, operator_state) = {
        let _ = (settings, origin, operator_state);
        (config::DEFAULTS, Origin::FirstBoot, None)
    };
    println!("settings: {:?}", origin);
    #[cfg(feature = "breadboard")]
    println!("BREADBOARD BUILD: STEP 18, DIR 8, no ENA (servo enables itself), encoder 21/15");
    setup::CURRENT.lock(|c| c.set(Some(settings)));

    // Mutable for the breadboard build's boot rainbow, which borrows RMT and DIR.
    #[allow(unused_mut)]
    let mut pins = take_pins!(p);
    // Breadboard build: GPIO17 (the RX pin) supplies 3.3 V to the encoder
    // pull-ups on the J3 side. Held high for good; off only while booting.
    // (`forget` so the pin stays driven even if `Output` ever resets on drop.)
    #[cfg(feature = "breadboard")]
    #[allow(clippy::forget_non_drop)]
    core::mem::forget(Output::new(p.GPIO17, Level::High, OutputConfig::default()));

    // Spindle encoder: count both edges of A, direction from B (2 counts per line).
    // Open-drain encoder: the internal pull-ups supply the high level.
    let pull_up = InputConfig::default().with_pull(Pull::Up);
    let encoder_a = Input::new(pins.encoder_a, pull_up);
    let encoder_b = Input::new(pins.encoder_b, pull_up);
    let pcnt = Pcnt::new(p.PCNT);
    let unit = pcnt.unit0;
    let limit = els_core::spindle::PCNT_LIMIT as i16;
    unit.set_low_limit(Some(-limit)).unwrap();
    unit.set_high_limit(Some(limit)).unwrap();
    unit.set_filter(Some(settings.encoder_filter_cycles)).unwrap();
    unit.clear();
    let ch = &unit.channel0;
    ch.set_edge_signal(encoder_a.peripheral_input());
    ch.set_ctrl_signal(encoder_b.peripheral_input());
    ch.set_input_mode(channel::EdgeMode::Decrement, channel::EdgeMode::Increment);
    ch.set_ctrl_mode(channel::CtrlMode::Reverse, channel::CtrlMode::Keep);
    unit.resume();

    let enabled = if settings.invert_enable { Level::Low } else { Level::High };
    let enable = pins.enable.map(|pin| Output::new(pin, enabled, OutputConfig::default()));
    // STEP idles inactive from here on, before the motion task takes it over.
    let step = Output::new(pins.step, step_levels(&settings).1, OutputConfig::default()).into_flex();
    // Breadboard build: GPIO8 is DIR, so the LED only gets a boot rainbow (on
    // a short-lived RMT driver, before the motion task takes RMT). DIR
    // toggles meanwhile, which is harmless with STEP held idle.
    #[cfg(feature = "breadboard")]
    {
        let rmt = Rmt::new(p.RMT.reborrow(), Rate::from_mhz(config::RMT_SOURCE_MHZ)).unwrap().into_async();
        let mut led = rmt.channel1.configure_tx(pins.dir.reborrow(), led::tx_config()).unwrap();
        led::boot_rainbow(&mut led, 1_500).await;
    }
    // Normal build: the LED task joins in once the motion task has set up RMT.
    #[cfg(all(feature = "esp32c6", not(feature = "breadboard")))]
    spawner.spawn(led::rainbow_task(p.GPIO8)).unwrap();
    // Flex so the hil build can read the pin back as well.
    let dir = Output::new(pins.dir, Level::Low, OutputConfig::default()).into_flex();
    #[cfg(feature = "hil")]
    let step_counter = hil::StepCounter::new(pcnt.unit1, step.peripheral_input(), dir.peripheral_input(), &settings);
    let hw = MotionHw {
        spindle: unit,
        rmt: p.RMT,
        step: step.into_peripheral_output(),
        #[cfg(feature = "hil")]
        step_counter,
        dir,
        _enable: enable,
        _encoder_a: encoder_a,
        _encoder_b: encoder_b,
    };

    static MOTION_EXECUTOR: StaticCell<InterruptExecutor<2>> = StaticCell::new();
    let motion_executor = MOTION_EXECUTOR.init(InterruptExecutor::new(sw.software_interrupt2));
    let motion_spawner = motion_executor.start(Priority::Priority3);
    motion_spawner.spawn(motion_task(hw, settings)).unwrap();

    let uart_config = uart::Config::default().with_baudrate(config::NEXTION_BAUD);
    let uart = Uart::new(p.UART1, uart_config).unwrap().with_tx(pins.nextion_tx).with_rx(pins.nextion_rx).into_async();
    spawner.spawn(display_task(uart)).unwrap();
    #[cfg(feature = "hil")]
    {
        let (usb_rx, _) = esp_hal::usb_serial_jtag::UsbSerialJtag::new(p.USB_DEVICE).into_async().split();
        spawner.spawn(hil::usb_rx_task(usb_rx)).unwrap();
        spawner.spawn(hil::report_task()).unwrap();
    }
    spawner.spawn(touch_task()).unwrap();
    spawner.spawn(ui_task(settings, origin, store, operator_state)).unwrap();
    spawner.spawn(setup::setup_task(spawner, p.WIFI)).unwrap();
    #[cfg(feature = "bench")]
    spawner.spawn(bench_task()).unwrap();
}

/// Repeating jog sequence for scoping STEP/DIR without a display: taps and
/// holds in both directions, injected as touch keys so it goes through the UI.
#[cfg(feature = "bench")]
#[embassy_executor::task]
async fn bench_task() {
    Timer::after_millis(config::NEXTION_BOOT_MS + 500).await;
    let steps: [(&str, bool, u64); 4] =
        [("tap right", false, 100), ("tap left", true, 100), ("hold right", false, 2_000), ("hold left", true, 2_000)];
    loop {
        for (name, left, press_ms) in steps {
            println!("bench: {}", name);
            KEYS.send(Key::Jog { left, pressed: true }).await;
            Timer::after_millis(press_ms).await;
            KEYS.send(Key::Jog { left, pressed: false }).await;
            Timer::after_millis(1_500).await;
        }
    }
}

/// Log Nextion traffic, one command per line (0xFF terminators dropped).
#[cfg(feature = "nextion-log")]
fn log_nextion(dir: &str, bytes: &[u8]) {
    for chunk in bytes.split(|&b| b == 0xFF).filter(|c| !c.is_empty()) {
        // Text is UTF-8; anything else (touch events) as hex escapes.
        if let Ok(s) = core::str::from_utf8(chunk) {
            if !s.is_empty() && !s.chars().any(char::is_control) {
                println!("nextion {}: {}", dir, s);
                continue;
            }
        }
        let mut line: heapless::String<256> = heapless::String::new();
        for &b in chunk {
            let _ = if b.is_ascii_graphic() || b == b' ' {
                line.push(b as char).map_err(|_| core::fmt::Error)
            } else {
                core::fmt::Write::write_fmt(&mut line, format_args!("\\x{:02x}", b))
            };
        }
        println!("nextion {}: {}", dir, line);
    }
}

/// Convert a planned segment into RMT pulse codes.
fn encode(segment: &Segment, cfg: &StepGenConfig, (on, off): (Level, Level), out: &mut Codes) {
    out.clear();
    for item in segment.items(cfg) {
        let code = if item.pulse == 0 {
            // Zero length marks the end of the transmission.
            PulseCode::new(off, item.idle, off, 0)
        } else {
            PulseCode::new(off, item.idle, on, item.pulse)
        };
        let _ = out.push(code);
    }
}

/// LP IO input register (GPIO0-7 as seen by the LP domain).
#[cfg(feature = "encoder-log")]
fn lp_in() -> u32 {
    #[cfg(feature = "esp32c6")]
    return unsafe { core::ptr::read_volatile(0x600B_2024 as *const u32) } & 0xff;
    #[cfg(not(feature = "esp32c6"))]
    0
}

/// Spindle position predicted `ahead_us` into the future from recent samples.
struct SpindlePredictor {
    history: [(u64, i64); config::SPINDLE_VELOCITY_SEGMENTS],
    next: usize,
}

impl SpindlePredictor {
    fn predict(&mut self, now_us: u64, counts: i64, ahead_us: u64) -> i64 {
        let (then_us, then_counts) = self.history[self.next];
        self.history[self.next] = (now_us, counts);
        self.next = (self.next + 1) % self.history.len();
        let dt = now_us.saturating_sub(then_us);
        if then_us == 0 || dt == 0 {
            return counts;
        }
        counts + (counts - then_counts) * ahead_us as i64 / dt as i64
    }
}

#[embassy_executor::task]
async fn motion_task(mut hw: MotionHw, settings: Settings) {
    let levels = step_levels(&settings);
    let stepgen_cfg = settings.stepgen(config::TIMING);
    // STEP pulses come from RMT channel 0; the pin idles inactive between segments.
    let rmt = Rmt::new(hw.rmt, Rate::from_mhz(config::RMT_SOURCE_MHZ)).unwrap().into_async();
    let mut step: rmt::Channel<'static, Async, rmt::Tx> = rmt
        .channel0
        .configure_tx(
            hw.step,
            TxChannelConfig::default()
                .with_clk_divider(config::RMT_DIVIDER)
                .with_idle_output(true)
                .with_idle_output_level(levels.1),
        )
        .unwrap();
    // Channel 1 is left to the LED task, which waits for this.
    #[cfg(all(feature = "esp32c6", not(feature = "breadboard")))]
    led::RMT_READY.store(true, core::sync::atomic::Ordering::Release);

    let machine = settings.machine();
    let segment_us = config::SEGMENT_US as u64;
    let mut spindle = Spindle::new(settings.encoder_backlash as i64);
    let mut predictor = SpindlePredictor { history: [(0, 0); config::SPINDLE_VELOCITY_SEGMENTS], next: 0 };
    let mut gearbox = Gearbox::new(machine);
    let mut stepgen = StepGen::new(stepgen_cfg);
    // Everything but the step generator works in carriage positions.
    let mut backlash = Backlash::new(settings.backlash_steps());
    let mut jog = Jog::new(settings.jog());
    let mut z_zero = 0i64;
    let mut turn_zero = 0i64;

    let mut rpm = 0u32;
    let mut rpm_start = (Instant::now().as_micros(), 0i64);
    let mut status_countdown = 0u32;

    // Pin levels sampled every segment, with software-counted A/B edges, to
    // compare against the PCNT count.
    #[cfg(feature = "encoder-log")]
    let mut enc_log = (0u64, hw._encoder_a.level(), hw._encoder_b.level(), 0u32, 0u32);
    #[cfg(feature = "encoder-log")]
    let (mut gpio_last, mut gpio_toggled) = (0u32, 0u32);
    // Largest following error (steps behind the gearbox) while engaged.
    #[cfg(feature = "encoder-log")]
    let mut max_lag = 0i64;
    // Longest loop period and how long the previous log line took to print.
    #[cfg(feature = "encoder-log")]
    let (mut last_now, mut max_dt, mut print_us) = (0u64, 0u64, 0u64);
    // Read the DIR pad back, to catch a pin held away from its driven level.
    #[cfg(feature = "encoder-log")]
    hw.dir.set_input_enable(true);
    // GPIO0-7 are LP pads on the C6: LP_AON_GPIO_MUX selects LP IO over the
    // HP IO_MUX/GPIO matrix. It survives HP-only resets.
    #[cfg(all(feature = "encoder-log", feature = "esp32c6"))]
    unsafe {
        let r = |a: usize| core::ptr::read_volatile(a as *const u32);
        println!(
            "encoder: lp_aon gpio_mux {:08x} gpio_hold0 {:08x} | io_mux gpio2 {:08x} gpio3 {:08x} | lp_io gpio2 {:08x} gpio3 {:08x}",
            r(0x600B_1028),
            r(0x600B_102C),
            r(0x6009_000C),
            r(0x6009_0010),
            r(0x600B_2050),
            r(0x600B_2054)
        );
    }
    #[cfg(feature = "encoder-log")]
    println!(
        "encoder: ppr {} filter {} backlash {} invert {}",
        settings.encoder_ppr, settings.encoder_filter_cycles, settings.encoder_backlash, settings.invert_spindle
    );
    #[cfg(feature = "encoder-log")]
    println!("settings: {:?}", settings);

    // Double buffer: `playing` is on the wire while `planned` is filled.
    let mut playing = Codes::new();
    let mut planned = Codes::new();
    let mut planned_positive = true;
    encode(&Segment::default(), &stepgen_cfg, levels, &mut planned);

    loop {
        core::mem::swap(&mut playing, &mut planned);
        // The previous segment has finished, so DIR can change now; the step
        // generator keeps the first STEP edge after a change DIR_SETUP_NS away.
        hw.dir.set_level(Level::from(planned_positive != settings.invert_dir));
        // Starts the hardware immediately; awaited at the end of the loop.
        let transmission = step.transmit(&playing);

        let now = Instant::now().as_micros();
        #[cfg(feature = "hil")]
        hw.step_counter.poll(stepgen.pos());
        let raw = hw.spindle.value();
        spindle.feed(if settings.invert_spindle { -raw } else { raw });
        // The segment being planned ends two segments from now.
        let s = predictor.predict(now, spindle.avg, 2 * segment_us);

        while let Ok(cmd) = COMMANDS.try_receive() {
            #[cfg(feature = "encoder-log")]
            println!(
                "motion: {:?} | pos {} engaged {} stops L {:?} R {:?}",
                cmd,
                backlash.carriage(stepgen.pos()),
                gearbox.engaged(),
                gearbox.stop(Side::Left),
                gearbox.stop(Side::Right)
            );
            match cmd {
                Command::SetPitchDu(du) => gearbox.set_pitch_du(du, s),
                Command::Engage => {
                    jog.cancel();
                    gearbox.engage(s, backlash.carriage(stepgen.pos()));
                    turn_zero = spindle.pos;
                }
                Command::Disengage => {
                    jog.cancel();
                    gearbox.disengage(backlash.carriage(stepgen.pos()));
                }
                Command::Jog { left, distance_du, level } if !gearbox.engaged() => {
                    let dir = if left { 1 } else { -1 };
                    let distance = machine.du_to_steps(distance_du);
                    jog.press(
                        dir,
                        distance,
                        level.into(),
                        backlash.carriage(stepgen.pos()),
                        stepgen.braking_steps(),
                        now,
                    );
                }
                Command::Jog { .. } => {}
                Command::JogRelease => jog.release(backlash.carriage(stepgen.pos()), stepgen.braking_steps(), now),
                Command::ToggleStop(side) => gearbox.toggle_stop(side, s, backlash.carriage(stepgen.pos())),
                Command::ZeroZ => {
                    // The UI refuses this while engaged with stops set.
                    z_zero = backlash.carriage(stepgen.pos());
                    gearbox.clear_stops();
                }
                Command::ZeroTurns => turn_zero = spindle.pos,
                Command::SetBacklashSteps(steps) => backlash.set_steps(steps),
            }
        }

        let target = if gearbox.engaged() {
            stepgen.set_speed_cap(None);
            gearbox.update(s)
        } else {
            let bounds = Bounds::new(gearbox.stop(Side::Right), gearbox.stop(Side::Left));
            let (target, cap) = jog.update(backlash.carriage(stepgen.pos()), bounds, now);
            stepgen.set_speed_cap(cap);
            target
        };
        let segment = stepgen.next_segment(backlash.motor_target(target));
        #[cfg(feature = "encoder-log")]
        if gearbox.engaged() && !target.is_final {
            let lag = target.pos - backlash.carriage(stepgen.pos());
            if lag.abs() > max_lag.abs() {
                max_lag = lag;
            }
        }
        planned_positive = segment.positive;
        encode(&segment, &stepgen_cfg, levels, &mut planned);

        if now - rpm_start.0 >= config::RPM_WINDOW_US {
            let counts = (spindle.pos - rpm_start.1).unsigned_abs();
            let elapsed = now - rpm_start.0;
            rpm = (counts * 60_000_000 / (machine.counts_per_rev as u64 * elapsed)) as u32;
            rpm_start = (now, spindle.pos);
        }
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

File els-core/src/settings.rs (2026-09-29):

//! Machine settings editable from the setup web page, and operator state
//! remembered across power cycles. Both are persisted with [`crate::record`].

use crate::jog::{JogConfig, JOG_LEVELS};
use crate::pitch::{Pitch, Unit, JOG_SIZES_MILLI, STEP_SIZES_MILLI};
use crate::record::{self, Loaded, Reader, Writer};
use crate::stepgen::{StepGenConfig, MAX_STEPS_PER_SEGMENT};
use crate::Machine;

pub const SETTINGS_MAGIC: u32 = u32::from_le_bytes(*b"LELS");
/// 2 added `backlash_du` (version 1 records load with no compensation).
pub const SETTINGS_VERSION: u16 = 2;
pub const STATE_MAGIC: u32 = u32::from_le_bytes(*b"LEOP");
pub const STATE_VERSION: u16 = 1;
/// Upper bound on an encoded record (header + payload) of either kind.
pub const MAX_RECORD_LEN: usize = 128;

/// Machine and motion settings. Pins are fixed in the firmware.
#[derive(Clone, Copy, Debug, PartialEq, Eq)]
pub struct Settings {
    pub encoder_ppr: u32,
    pub encoder_backlash: u32,
    pub encoder_filter_cycles: u16,
    pub invert_spindle: bool,
    pub screw_du: u32,
    pub motor_steps: u32,
    pub speed_start: u32,
    pub speed_max: u32,
    pub acceleration: u32,
    pub max_pitch_du: u32,
    pub invert_dir: bool,
    pub invert_enable: bool,
    pub step_active_low: bool,
    pub step_pulse_ns: u32,
    pub dir_setup_ns: u32,
    pub jog_speeds_du_per_s: [u32; JOG_LEVELS],
    pub jog_hold_after_ms: u32,
    pub jog_level_every_ms: u32,
    /// Lead screw backlash, compensated on every reversal.
    pub backlash_du: u32,
}

/// Fixed motion timing from the firmware, needed to validate settings.
#[derive(Clone, Copy, Debug)]
pub struct Timing {
    pub tick_hz: u32,
    pub segment_ticks: u32,
}

/// Where the settings in use came from.
#[derive(Clone, Copy, Debug, PartialEq, Eq)]
pub enum Origin {
    Saved,
    /// Nothing saved yet: firmware defaults.
    FirstBoot,
    /// Saved data was damaged or failed validation: firmware defaults.
    Corrupt,
    /// Saved by a newer firmware with an unknown format: firmware defaults.
    Unsupported,
}

impl Settings {
    pub fn machine(&self) -> Machine {
        Machine {
            counts_per_rev: self.encoder_ppr as i64 * 2,
            motor_steps: self.motor_steps as i64,
            screw_du: self.screw_du as i64,
        }
    }

    pub fn stepgen(&self, t: Timing) -> StepGenConfig {
        let ticks = |ns: u32| (ns as u64 * t.tick_hz as u64).div_ceil(1_000_000_000) as u32;
        StepGenConfig {
            tick_hz: t.tick_hz,
            segment_ticks: t.segment_ticks,
            pulse_ticks: ticks(self.step_pulse_ns).max(1),
            dir_setup_ticks: ticks(self.dir_setup_ns),
            start_speed: self.speed_start,
            max_speed: self.speed_max,
            acceleration: self.acceleration,
        }
    }

    /// Backlash compensation in motor steps.
    pub fn backlash_steps(&self) -> i64 {
        self.machine().du_to_steps(self.backlash_du as i64)
    }

    pub fn jog(&self) -> JogConfig {
        let m = self.machine();
        JogConfig {
            hold_after_us: self.jog_hold_after_ms as u64 * 1_000,
            level_every_us: self.jog_level_every_ms as u64 * 1_000,
            speeds: self.jog_speeds_du_per_s.map(|du| m.du_to_steps(du as i64).clamp(1, self.speed_max as i64) as u32),
        }
    }

    /// Check every field's range and the combinations the motion code relies on.
    pub fn validate(&self, t: Timing) -> Result<(), &'static str> {
        for f in FIELDS {
            let v = (f.get)(self);
            if v < f.min || v > f.max {
                return Err(f.label);
            }
        }
        if self.speed_start > self.speed_max {
            return Err("Start speed must not exceed max speed");
        }
        let g = self.stepgen(t);
        if self.speed_max > g.pulse_limited_speed() {
            return Err("STEP pulse too wide for max speed");
        }
        if g.max_steps_per_segment() > MAX_STEPS_PER_SEGMENT as u64 {
            return Err("Max speed too high for the control period");
        }
        if g.dir_setup_ticks >= g.segment_ticks / 2 {
            return Err("DIR setup time too long");
        }
        Ok(())
    }
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

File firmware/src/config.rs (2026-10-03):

//! Everything specific to your board, plus the machine defaults. Machine
//! settings can also be changed at runtime from the setup web page.

use els_core::settings::{Settings, Timing};

// ---------------------------------------------------------------------------
// Pinout
// ---------------------------------------------------------------------------

/// Board pins, taken out of `Peripherals` with `take_pins!`.
pub struct Pins {
    pub encoder_a: esp_hal::gpio::AnyPin<'static>,
    pub encoder_b: esp_hal::gpio::AnyPin<'static>,
    pub step: esp_hal::gpio::AnyPin<'static>,
    pub dir: esp_hal::gpio::AnyPin<'static>,
    /// Driver enable, if the build has one.
    pub enable: Option<esp_hal::gpio::AnyPin<'static>>,
    pub nextion_tx: esp_hal::gpio::AnyPin<'static>,
    pub nextion_rx: esp_hal::gpio::AnyPin<'static>,
}

/// ESP32-C6-DevKitC-1 (primary target). Encoder A/B/Z and Nextion on J1/J3,
/// driver on J3 18-20. Avoid strapping pins 4, 5, 8, 9, 15, USB 12/13, the
/// console UART 16/17 and flash 24-30. GPIO7 is kept free for encoder Z
/// (index), which the firmware doesn't read yet. GPIO2/3 took 5 V pull-ups
/// and may be damaged.
///
/// S2-SVD servo: STEP/DIR sink the drive's opto inputs directly, no level
/// shifter: CN2 PP+ (3) and PD+ (4) to 3V3, PP- (14) to STEP, PD- (5) to DIR,
/// GND (1) to GND. ENA is unused (the drive's enable needs 24 V): set
/// Pn003 = 1 so the drive enables itself at power-up.
///
/// Drive tuning on this machine: Fn018 inertia ratio ~1.5 (hands off the
/// carriage) in Pn257, automatic gains (Pn258), rigidity Pn259 = 8 (9 and up
/// hums), online inertia estimation off (Pn260 = 0), command smoothing off
/// (Pn109 = 0). Save with Fn001 and power-cycle.
#[cfg(all(feature = "esp32c6", not(feature = "breadboard")))]
macro_rules! take_pins {
    ($p:ident) => {
        $crate::config::Pins {
            encoder_a: esp_hal::gpio::Pin::degrade($p.GPIO10),
            encoder_b: esp_hal::gpio::Pin::degrade($p.GPIO11),
            step: esp_hal::gpio::Pin::degrade($p.GPIO18),
            dir: esp_hal::gpio::Pin::degrade($p.GPIO19),
            enable: Some(esp_hal::gpio::Pin::degrade($p.GPIO20)),
            nextion_tx: esp_hal::gpio::Pin::degrade($p.GPIO22),
            nextion_rx: esp_hal::gpio::Pin::degrade($p.GPIO23),
        }
    };
}

/// BREADBOARD BUILD (`--features breadboard`), for test-driving on a solder
/// breadboard. Not for a PCB.
///
/// A 74HCT125 (VCC 5 V) sits in the valley under the DevKitC-1 with pin 14
/// on the 5V row, so every IC pin shares a strip with a header pin:
///
/// | IC pin | strip    | use                                            |
/// |--------|----------|------------------------------------------------|
/// | 14 VCC | 5V       | supply, 100 nF to pin 7                        |
/// | 5  2A  | GPIO18   | STEP in                                        |
/// | 6  2Y  | GPIO19   | STEP out to CN2 14 (PP-); cut DevKit pin 19    |
/// | 4  2OE | GPIO9    | tied to GND (always on); cut DevKit pin 9      |
/// | 9  3A  | GPIO8    | DIR in                                         |
/// | 8  3Y  | GPIO1    | DIR out to CN2 5 (PD-); cut DevKit pin 1       |
/// | 10 3OE | GPIO10   | tied to GND (always on); cut DevKit pin 10     |
/// | 7  GND | GPIO20   | jumpered to a G pin; GPIO20 unused (never      |
/// |        |          | driven: it's ground now)                       |
/// | 1, 13  | 12, 3    | tied to pin 14 (channels 1, 4 off)             |
/// | 2, 12  | 13, 2    | tied to GND                                    |
/// | 3, 11  | G, 11    | cut off                                        |
///
/// Cut the DevKit's header pins 1, 2, 3, 9, 10, 12, 13 and 19 before fitting
/// it: their strips carry 5 V, GND or the buffer's 5 V outputs. 5 V on
/// GPIO12 (USB D-) killed a board, and GPIO9 grounded is the BOOT strap
/// held low, so the chip starts in download mode and looks dead. USB
/// doesn't need the header pins.
/// Servo-side wiring and wire colours: README, "Breadboard build: servo
/// wiring", and docs/images/cn2-wiring.svg.
///
/// CN2 PP+ (3) and PD+ (4) go to 5V. The encoder moves to GPIO21/15
/// (GPIO10/11 are taken, and GPIO0-7 are LP pads, see encoder-log), each
/// with its own 4.7k pull-up to GPIO17 (the RX pin), which the firmware
/// holds high as a 3.3 V supply on the J3 side (about 1.4 mA).
///
/// No ENA: the S2-SVD's enable input (CN2 6, SigIn1) needs its 24 V I/O
/// supply, which this 5 V-only setup doesn't have, so it isn't used. Set
/// Pn003 = 1 and the drive enables itself at power-up.
#[cfg(all(feature = "esp32c6", feature = "breadboard"))]
macro_rules! take_pins {
    ($p:ident) => {
        $crate::config::Pins {
            encoder_a: esp_hal::gpio::Pin::degrade($p.GPIO21),
            encoder_b: esp_hal::gpio::Pin::degrade($p.GPIO15),
            step: esp_hal::gpio::Pin::degrade($p.GPIO18),
            dir: esp_hal::gpio::Pin::degrade($p.GPIO8),
            enable: None,
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

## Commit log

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2026-09-25 Add left/right jog: tap moves jog distance, hold ramps through speed levels
    Also document open-drain encoder pull-ups.
2026-09-25 Generate STEP pulses with RMT from a segment planner; make ESP32-C6 primary
    - StepGen plans 250 µs segments with velocity feed-forward and a
    braking-limited correction; RMT plays each segment at 100 ns resolution
    - Gearbox target carries the fractional step for even pulse spacing
    - Spindle position predicted to the end of the planned segment
    - Pinout and all timing moved into config.rs with compile-time checks
    - C6 is the default target on stable Rust; S3 via cargo +esp s3
    [config.rs, gearbox.rs, lib.rs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]
2026-09-25 Add CI: core tests and firmware builds for ESP32-C6 and ESP32-S3
    Also add rustfmt.toml and format both crates.
2026-09-25 WiFi setup portal and persisted settings
    - Setup button (disengaged only) starts a WPA2 hotspot with DHCP (captive
    portal option), catch-all DNS and a settings page; saving writes flash
    and restarts with WiFi off
    - Settings and operator state stored as versioned records with magic,
    length, sequence and CRC32 in alternating flash slots
    - Pitch, unit and step sizes survive power-off (saved when idle)
    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
2026-09-25 Match firmware to the Lee-LS Nextion HMI
    - key_for uses the Lee-LS component ids (1-33); new Key::ToggleEngage,
    Key::PitchPreset and Key::BackspaceReleased
    - Text goes to the new objnames with labels (tRPM "RPM 300", tZPos
    "Z POS 1.000mm", ...); messages move to tMessageLine (40 chars)
    - Stop buttons show three states (Set stop / stop Z / AT STOP) with
    WCAG AAA colour pairs sent as bco/pco; an armed stop can only be
    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
2026-09-26 Nextion: replace STEP CYCLE with 0.05 / 0.5 / 5.0 pitch presets
    New HMI and compiled TFT. bStepCycle (id 22) is deleted, so every later
    component shifts down by one; bPitch005, bPitch05 and bPitch5 are added
    as ids 33-35. The TFT was checked against the HMI: all 35 component
    geometries are present in id order.
2026-09-26 Map the 0.05 / 0.5 / 5.0 pitch presets; renumber ids after bStepCycle
    - nextion::id: bStepCycle is gone, so tPitch..tMessageLine shift down one
    (22-32); bPitch005/05/5 are 33-35 and map to PitchPreset(50/500/5_000).
    - Tests cover all six presets; captured trace uses the new bZeroZ id.
    - docs/nextion.md, nextion/README.md and README.md updated to match.
2026-09-26 C6: real DevKitC-1 pinout; move STEP/DIR/ENA off strapping pins
    STEP/DIR/ENA move from GPIO4/5/6 (4 and 5 are MTMS/MTDI strapping pins)
    to GPIO18/19/20 on header J3. Encoder A/B stay on 2/3; GPIO7 is reserved
    for encoder Z. Nextion stays on 22/23.
2026-09-26 Fix jog hold never moving: lookahead overflowed StepGen's fixed point
    HOLD_LOOKAHEAD was 1 << 40 steps; StepGen shifts targets left by 32, so a
    hold target wrapped to about zero and the carriage sat still while the
    display showed HOLD SPEED. Use 1 << 24 and test a hold through StepGen.
    [stepgen.rs]
2026-09-26 Bench and hardware-in-the-loop firmware builds, host HIL tests
    bench: hotspot at boot, Nextion UART traffic logged, repeating jog
    sequence on STEP/DIR for a scope.
    hil: touch events over USB-Serial-JTAG into the same buffer the Nextion
    UART fills, display commands and STEP pulse counts (second PCNT unit on
    the STEP pin, inside the chip) in the log. hil/ resets the board, taps
    components by HMI object name and asserts on what the display is told and
    on planned vs. emitted steps.
    [display.rs, lib.rs, main.rs]
2026-09-27 Lock the screen in setup; symbols for pitch/Z; stops show distance to go
    - Setup mode: every touchable component but bSettings gets tsw 0 and
    near-black colours, and the UI ignores keys other than Setup (releases
    still pass). Boot sends page 0 so an ESP32-only restart restores the
    HMI's colours and touch.
    - Text goes as UTF-8 (both HMI fonts are UTF-8); the 0xDF degree hack is
    gone. tPitch/tZPos lead with ↻ / ⇄ instead of PITCH / Z POS, and tZPos
    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
2026-09-27 C6: encoder on GPIO10/11, S2-SVD servo wired direct; encoder-log feature
    GPIO2/3 never saw the encoder (likely damaged by 5 V pull-ups), so the
    encoder moves to 10/11. STEP/DIR/ENA stay on 18/19/20 and drive the
    S2-SVD servo's opto inputs directly: a level shifter between them could
    not hold the off level against the opto, causing stray steps and left
    jogs that cancelled out. config.rs documents the CN2 wiring and Pn003.
    encoder-log (off by default) logs pin levels, software-counted edges,
    PCNT count, RPM, GPIO/LP input registers, DIR pad readback and motion
    commands, for bench bring-up.
    [config.rs, main.rs]
2026-09-27 C6 defaults: 2 mm lead screw, S2-SVD servo at 10000 pulses per turn
    Measured lead is 2 mm. The servo's default 1:1 electronic gear takes
    10000 pulses per motor turn; the old 800-step stepper defaults moved
    the carriage 8% of the commanded distance. Max speed 100k steps/s
    (20 mm/s, under the ~124k segment limit), acceleration 200k steps/s².
2026-09-27 Rejoin the thread on re-engage; faster acceleration to follow spindle load
    Engaging used to start a new thread at whatever phase the spindle was in,
    so a second pass after jogging back cut a new groove. The gearbox now keeps
    its reference line while disengaged and, on engage at the same pitch, holds
    (Syncing) until the spindle reaches that thread's phase at the carriage's
    position. Changing the pitch while disengaged starts a new thread;
    selecting the same pitch again keeps it. Single-start threads only.
    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
2026-09-28 Record S2-SVD drive tuning; encoder-log times the motion loop
    config.rs notes the drive settings arrived at on this machine: inertia
    ratio ~1.5 (Fn018, hands off), automatic gains, rigidity Pn259 = 8
    (higher hums), online estimation and command smoothing off.
    encoder-log now reports the longest motion loop period and how long its
    own log line took to print, to check whether printing (esp-println holds
    a critical section) stalls the motion loop.
    [config.rs, main.rs]
2026-09-29 Nextion at 115200 via a boot handshake; fix half-sent lock commands
    - Boot sends baud=115200 at the HMI's 9600, then switches.
    - page 0 at boot is preceded by a bare terminator: after an ESP32-only
    restart (leaving setup) the handshake reaches a display already at
    115200 as noise, which swallowed the page reload.
    - Setup lock commands for long names overflowed a 64-byte buffer and
    went out half-written (0x1A from the display, buttons partly locked).
    Bigger buffers, and encoders now append nothing when a command doesn't
    fit.
    [config.rs, main.rs]
2026-09-29 Lead screw backlash compensation, with a measuring wizard
    - els-core backlash: the motor runs the backlash further on each
    reversal (1-step hysteresis). Gearbox, jog, stops and the Z readout
    stay in carriage positions; only StepGen sees motor positions.
    - Settings v2 adds backlash_du (v1 records load with 0).
    - Setup page: /backlash wizard for a dial indicator. Takes up the slack
    1 mm left, reverses 0.5 mm, asks for the reading; each round runs with
    the estimate so far on and refines it, then saves and restarts.
    [backlash.rs, config.rs, lib.rs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]
2026-09-29 Invert DIR help: it's about jog direction, not pitch sign
    [settings.rs]
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2026-10-02 Proof-of-life rainbow on the DevKitC-1 RGB LED (GPIO8)
    Normal build: a slow rainbow from a thread-executor task for as long as the
    firmware runs, so a hang freezes the colour. RMT channel 1 drives the LED;
    the motion task keeps channel 0 for STEP and signals once RMT is set up.
    Breadboard build: GPIO8 is DIR there, so the rainbow only plays for 1.5 s at
    boot on a short-lived RMT driver, with ENA holding the 74HCT125's outputs
    off, before the pin becomes DIR.
    Also: examples/rainbow.rs as a standalone board check; clippy's
    forget_non_drop allowed on the breadboard pins held high; encoder-log
    prints all settings at boot.
    [led.rs, main.rs, rainbow.rs]
2026-10-03 README: S2-SVD CN2 wiring diagram for the breadboard build; cut six DevKit pins
    docs/images/cn2-wiring.svg shows the DB25 face with wire colours and the five breadboard connectors (POWER, COM, STEP, DIR, ENA) to CN2 and the ESP32 pins. config.rs no longer calls GPIO19/1 unused: their strips carry the 74HCT125's 5 V outputs, so the DevKit's header pins 1, 2, 3, 12, 13 and 19 must be cut.
    [config.rs]
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2026-10-03 Breadboard: drop ENA; resync the display baud; bench jogs again
    - Breadboard build has no ENA: the S2-SVD's enable needs 24 V, which this
    5 V-only setup doesn't have (Pn003 = 1, the drive enables itself). The
    74HCT125's OE pins are tied to GND and DevKit header pins 9 and 10 are
    cut too: a grounded GPIO9 strip held the BOOT strap low, so the C6
    started in download mode and looked dead. The GPIO11 servo-enable
    output is gone. Pins.enable is optional; STEP is held idle from early
    boot so the boot rainbow toggling DIR can't step.
    - display_task owns the whole display UART and repeats the 9600 -> 115200
    handshake every 3 s while idle, so a display that rebooted on its own
    comes b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
    [config.rs, led.rs, main.rs]
2026-10-05 Breakout board schematic for the C6 DevKitC-1 (KiCad)
    Piggyback board on the DevKit's headers, all through-hole, normal C6
    pinout. STEP/DIR through a 74AHCT125 at 5 V into the servo optos with
    boot-time pull-ups; optional NPN for servo ENA (SigIn1); encoder A/B/Z
    with 4k7 pull-ups; Nextion JST-XH; 5 V in via a Schottky; shield GND
    terminal. ERC clean. The DevKit footprint is still to do.
    [leels-breakout.kicad_pcb, leels-breakout.kicad_sch]
2026-10-05 Breakout: Espressif's DevKitC-1 symbol and footprint for U1
    Use PCM_Espressif:ESP32-C6-DevKitC-1 (headers 22.86 mm apart, J3 pads
    numbered 17-32 bottom to top) instead of the hand-made symbol, with the
    nets reattached in Espressif's numbering and PWR_FLAGs on the rails.
    ERC clean, no unconnected pins or orphan labels.
    [leels-breakout.kicad_sch]
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2026-10-05 Breakout schematic: laid out by function, wired, labels only for ENC_Z
    Encoder and power in on the left, the DevKit in the middle, the servo
    chain (pull-ups, 74AHCT125, ENA transistor, terminal) and Nextion on the
    right. Real wires and power symbols throughout; the only labels are the
    ENC_Z global labels, which cross the sheet. PWR_FLAGs in their own block,
    notes and title block. ERC clean, no orphans or unconnected pins.
    [leels-breakout.kicad_sch]
2026-10-06 Breakout PCB: placement, routing and DRC-clean board
    - build_pcb.py builds the board from the schematic netlist: outline (stops
    at the DevKit's PCB edge, nothing under the antenna), placement with
    the buffer and passives under the DevKit, terminals facing the edges,
    GND pours on both layers and stitching vias.
    - route.py round-trips through Freerouting (Specctra DSN/SES); GND is
    left to the pours.
    - leels.pretty: Espressif's DevKitC-1 footprint with the courtyard
    limited to the socket rows.
    - Q1 on TO-92_Inline_Wide (the narrow one breaks 0.25 mm clearance).
    - Net classes: 0.3 mm signals, 0.6 mm power and ground.
    DRC: 0 violations, 0 unconnected, 0 schematic parity issues.
    Co-Auth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
    [leels-breakout.kicad_pcb, leels-breakout.kicad_sch]
2026-10-06 Breakout PCB: caps out from under the DevKit, connector silkscreen
    - C1/C2 move below the DevKit (too tall for the ~7 mm under it), next to
    the 5 V input.
    - Pin labels beside every terminal and the Nextion header (the display's
    pin names), group titles, board name and orientation on the back.
    - Re-routed; DRC 0 violations, 0 unconnected, 0 parity issues.
    [leels-breakout.kicad_pcb]
2026-10-06 Breakout PCB review fixes: terminals face out, real track widths
    - Every screw terminal opened towards the DevKit (checked in a 3D
    render); turned all four 180 degrees so wires enter from the edges.
    - The routed board was 0.2 mm everywhere: standalone pcbnew doesn't put
    the project's net classes into the DSN. route.py now writes the DSN net
    classes itself: 0.6 mm power, 0.3 mm signals, 0.25 mm clearance.
    - Connector references to F.Fab (titles name them), two more stitching
    vias, 3D render added.
    DRC: 1 warning (J5 GND thermal on B.Cu, connected via F.Cu), 0
    unconnected, 0 parity issues.
    [leels-breakout.kicad_pcb]
2026-10-06 Breakout rev A: encoder RC filters, Nextion before D1, Dupont header, holes
    - Encoder A/B/Z: 220R series at the terminal, 220p to GND at the GPIO
    (with the existing 4k7 pull-up), for noise and ESD.
    - Nextion power (J5, new J7) on 5V_IN ahead of D1: no Schottky drop for
    the display; it needs J4 power.
    - J7: 1x4 2.54 mm header in parallel with the JST for Dupont plugs.
    - C1 axial (laid flat) right at U2's supply pin; Q1 laid flat
    (TO-92 staggered horizontal, clearance-safe).
    - Three M3 mounting holes; board 51 x 70.1 mm.
    DRC: 1 warning (U2 pin 12 thermal on F.Cu, connected via B.Cu), 0
    unconnected, 0 parity issues; ERC clean.
    [leels-breakout.kicad_pcb, leels-breakout.kicad_sch]
2026-10-06 Breakout: 1.0 mm holes / 1.7 mm pads for the DevKit sockets
    Standard female headers (as in KiCad's PinSocket footprints) need 1.0 mm
    holes; Espressif's footprint had 0.8 mm. Re-routed; DRC 1 warning (U1
    pin 15 thermal on F.Cu, connected via B.Cu), 0 unconnected, 0 parity.
    [leels-breakout.kicad_pcb]
